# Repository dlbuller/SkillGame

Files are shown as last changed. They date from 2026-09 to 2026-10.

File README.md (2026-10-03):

<div align="center">

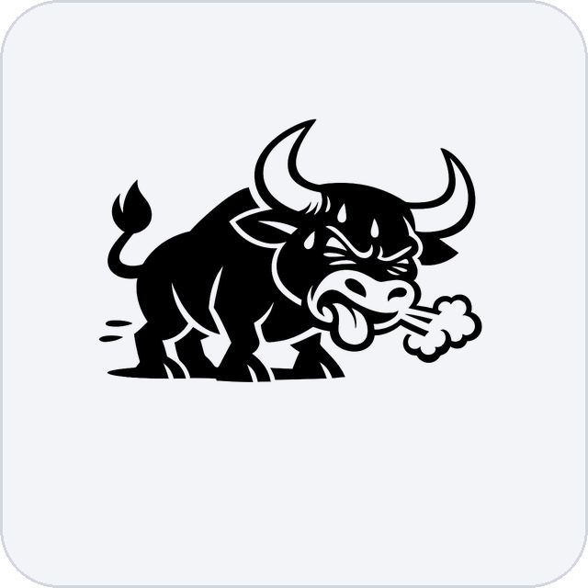
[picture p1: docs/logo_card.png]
WezeBull Games


# SkillGame

**A modern recreation of the 1955 [Bally Skill-Roll](https://www.ipdb.org/machine.cgi?id=4331) coin-roll arcade game** — real coin, real hardware, modern brains.

`ALL HUFF · NO BULL` — WezeBull Games







</div>

---

The player rolls a physical coin up the playfield. It rides the rails, skims the scoring holes, and drops into one to score. Climb the levels without losing the coin to a **gobble hole** — or **tilting** — and you win. A mini-PC runs the whole machine over four FT232H boards and shows the backglass, diagnostics and operator console on a touch monitor.

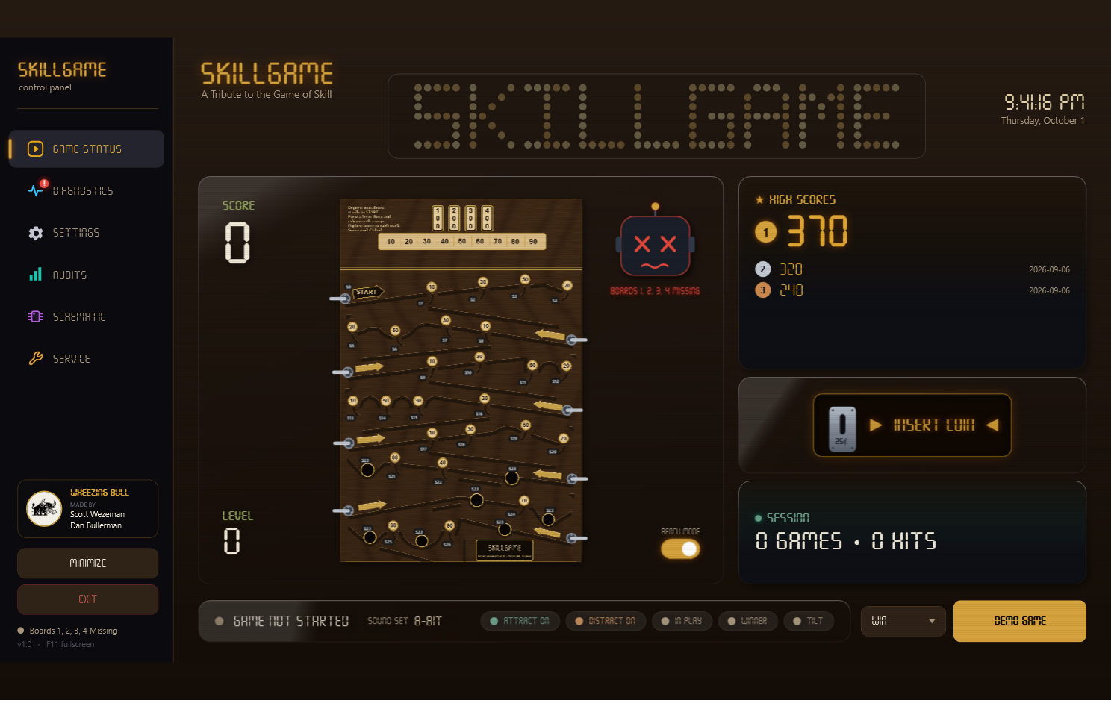
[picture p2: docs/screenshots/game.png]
Game Status


## Contents

- [How it plays](#how-it-plays) · [Features](#features) · [Screens](#screens) · [Themes](#themes) · [Hardware](#hardware) · [Build the board](#build-the-board) · [Software updates](#software-updates) · [Build &amp; run the app](#build--run-the-app) · [Layout](#layout)

## How it plays

1. **Insert a coin** — a real coin drops through the mech and arms a shot.
2. **Roll it up the playfield.** The coin rides *on top* of the rails and skims across the scoring holes.
3. **Drop it in a hole to score** — `10`–`90`, then the big `100 / 200 / 300 / 400` reels.
4. **Beware the gobble holes.** As you climb into the danger levels the machine flashes its lights and plays a **distract** effect *before* your shot — a real Skill-Roll trick to make you flinch. A miss ends the game.
5. **Land the Winner hole to win.** Tilt the machine too hard and it's game over.

## Features

- 🎯 **Game Status backglass** — live score, level, lamps and the coin animation, driven by the real switch reads.
- 🔧 **Diagnostics** — a live switch map and lamp map, a one-touch **Self-Test** that lights every lamp / pulses the coils / sweeps the LED strip, per-lamp **Identify** blink, and **stuck-switch** detection that turns a tile solid red.
- 📊 **Audits** — plays, wins, hits, high scores and time played, watched over by the auditor gremlin. Demo/attract games are excluded, so the numbers only count real play.
- 🛠️ **Service** — a single-screen operator console for volume, quiet hours, tilt sensitivity and the rest.
- 🎨 **12 themes** — Classy, Fun, Plain, Blackout, Vintage, Maple, Midnight, Synthwave, Lava, Circuit, Galaxy, Ruby; each reskins the whole UI *and* the playfield art. (Settings → Theme)
- ⬆️ **In-app software updates** — checks the WezeBull server, shows the release notes, and installs **any** version forward or back (Service → Check for Updates); it flags new versions on boot. Updates are unzip-and-copy + relaunch — no PC reboot.
- 🗺️ **Interactive schematic page** — a clickable system diagram with crossing-free animated wiring, plus one-tap access to the BOM, fuses, system hookup, full schematic, FT232H pinout and a 3D board viewer.
- 👻 **Attract / demo mode** — with no boards attached the app plays itself, so you can see the whole thing run on a laptop.
- ✅ **56 unit tests** over the game core — scoring, levels, tilt, coin gate, the spring-return lock pulses, stuck detection and the switch router.

## Screens

| | |
|---|---|
| **Schematic** — interactive, clickable system diagram | **Diagnostics** — live switch + lamp maps, self-test |
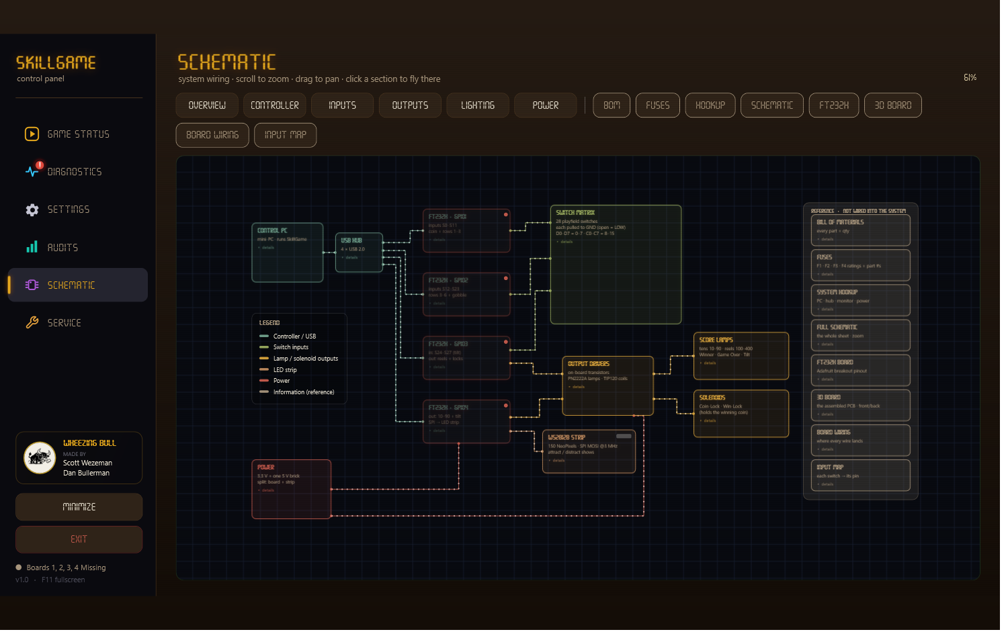
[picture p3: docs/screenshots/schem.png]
Schematic
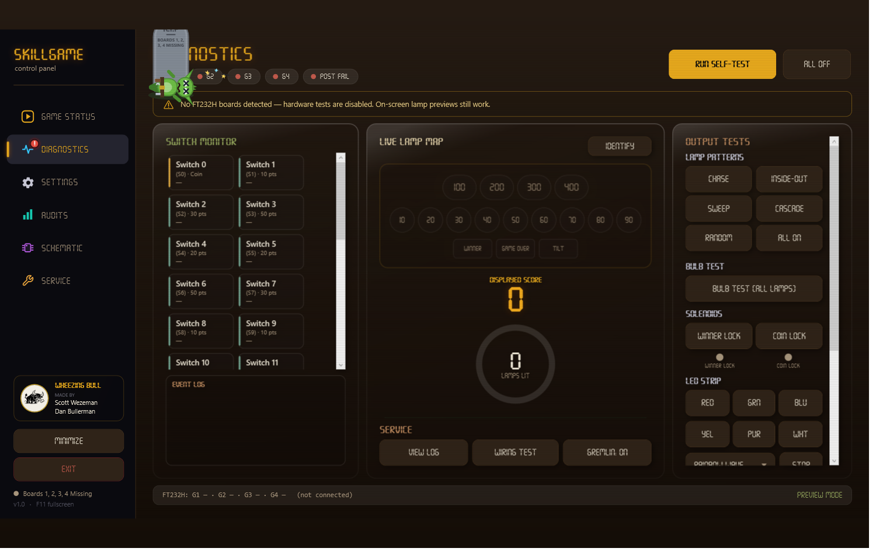
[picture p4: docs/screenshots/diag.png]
Diagnostics
|  |  |
| **Audits** — plays, wins, hits, high scores (the gremlin) | **Service** — one-page operator console |
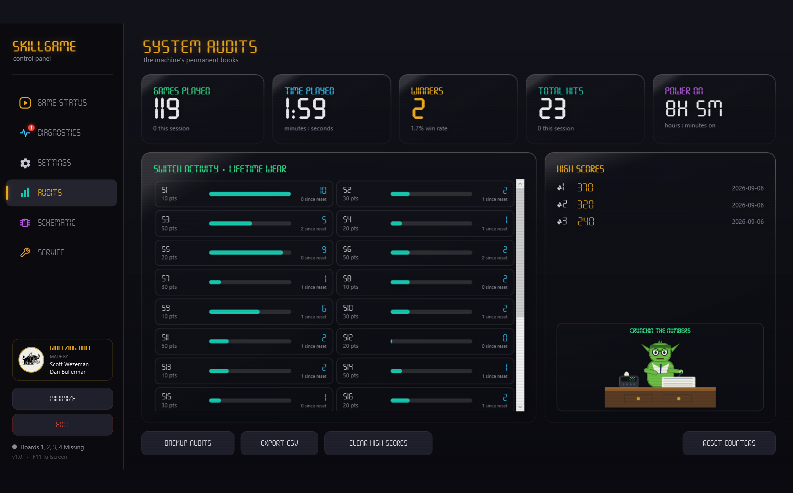
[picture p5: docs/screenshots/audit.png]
Audits
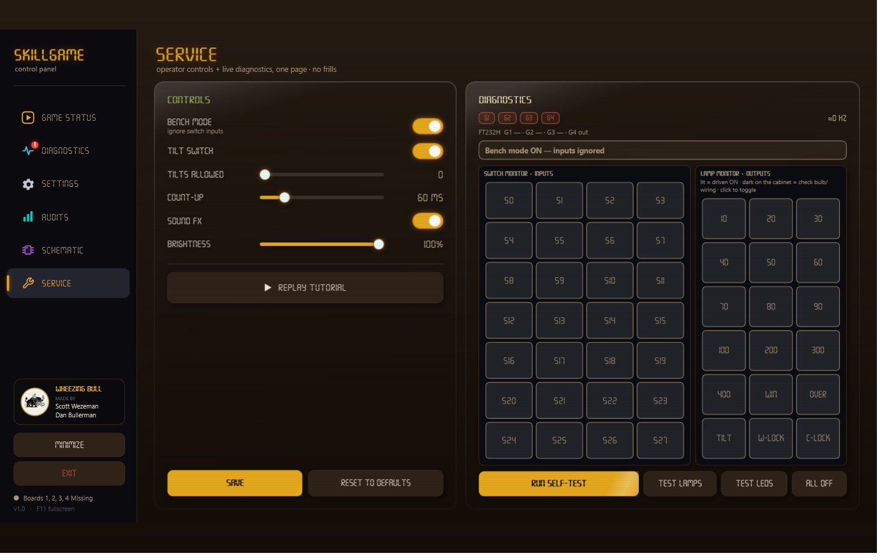
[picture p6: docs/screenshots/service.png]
Service
|  |  |

## Themes

Pick a look in **Settings → Theme**. Each of the **12 themes** reskins the whole UI *and* the playfield art — and every board below is geometry-matched to the original, so the coin paths never move:

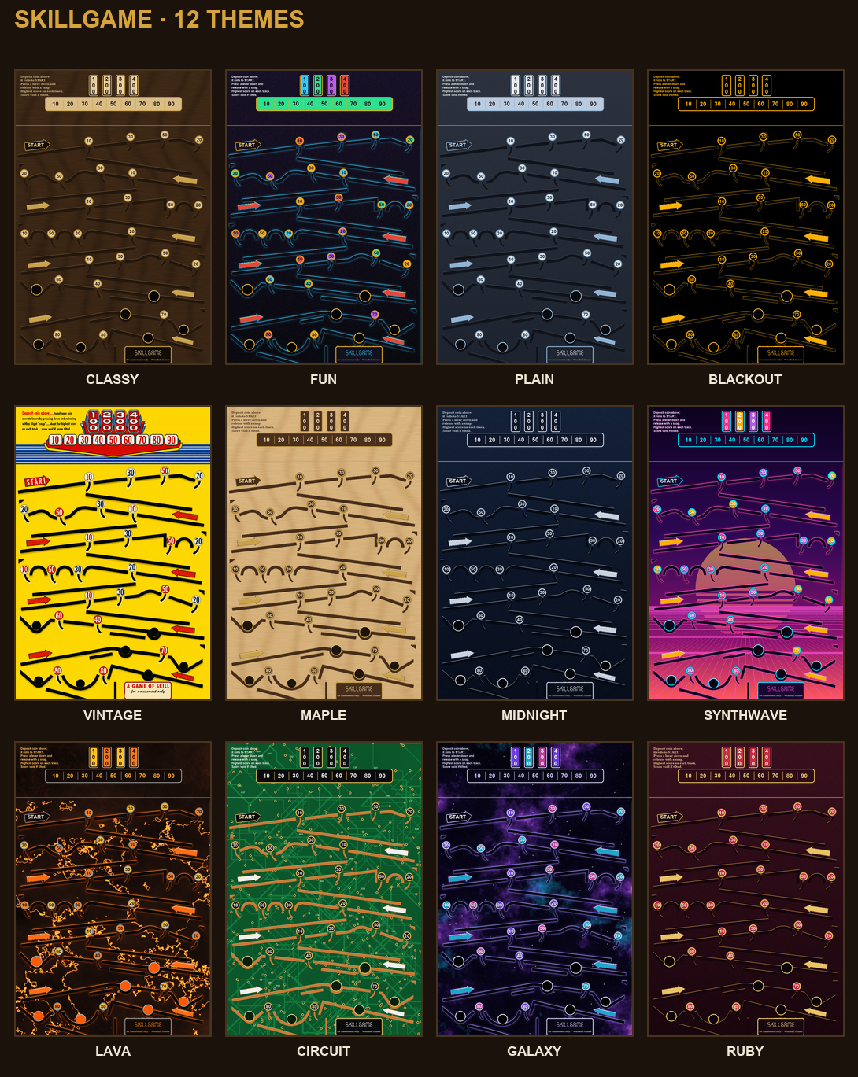
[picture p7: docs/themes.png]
SkillGame themes


**Classy** (walnut &amp; brass, the default) · **Fun** (arcade neon) · **Plain** (cool slate) · **Blackout** (OLED black &amp; amber) · **Vintage** (the 1949 look) · **Maple** · **Midnight** (navy &amp; chrome) · **Synthwave** · **Lava** · **Circuit** · **Galaxy** · **Ruby** (garnet &amp; gold).

## Hardware

The control board is a custom KiCad 9 design driven by **four Adafruit FT232H** breakouts over USB (MPSSE mode). Everything the software touches maps 1:1 to a real pin.

| Section | What it does |
|---|---|
| **Inputs** | 28 switches on GPIO1–3 (S23 = 7 parallel gobble holes). Commons run on 3.3 V — the FT232H inputs are **not** 5 V-tolerant. |
| **Score lamps** | 16 lamps via PN2222A drivers → 16 off-board **#555 wedge LED bulbs**. |
| **Solenoids** | Coin-Lock + Winner-Lock — **spring-return** coils (plunger out at rest blocks a coin with no power; a brief **pulse** retracts it to drop the coin, never held). TIP120 Darlingtons with 1N4004 flyback, fused (F1/F2 T2A). |
| **LED strip** | 150-pixel WS2812b on GPIO4's SPI line, on its own 5 V feed. |
| **Power** | 3.3 V → J1 (switch commons). One 5 V / 10 A brick splits into two fused branches — **F3** (T3.5A) → J3 (lamps + coils, ~2.7 A) and **F4** (T5A) → the strip's own LED± feed (~3.6 A, firmware brightness-capped). The strip never runs through the board. |

**The lamps are LEDs, wired honestly.** Each score lamp is a non-polar #555 wedge LED bulb in a twist-lock socket. Because the bulb is pre-resistored, the board's lamp positions (R30–R62) are **0 Ω links** — and a 6.3 V bulb on the 5 V rail runs safely under-driven. The **100 / 200 / 300 / 400** holes each drive **two** bulbs in parallel for double brightness.

| Score-lamp bulbs (schematic) | Board (3D) | System hookup |
|---|---|---|
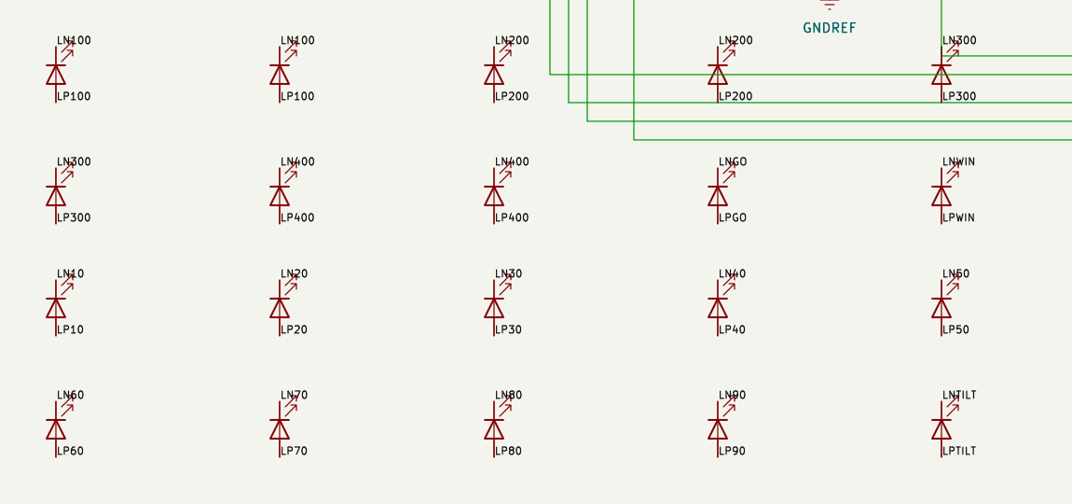
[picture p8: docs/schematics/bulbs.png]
Lamp bulbs
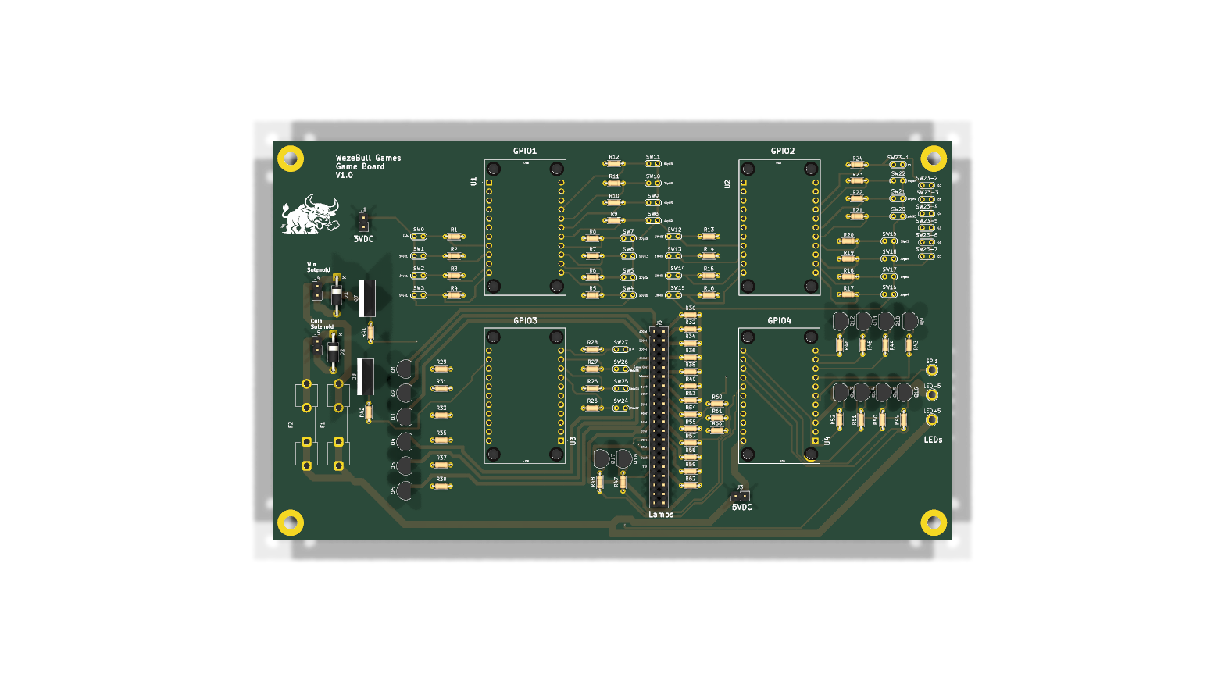
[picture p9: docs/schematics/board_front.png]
Board front
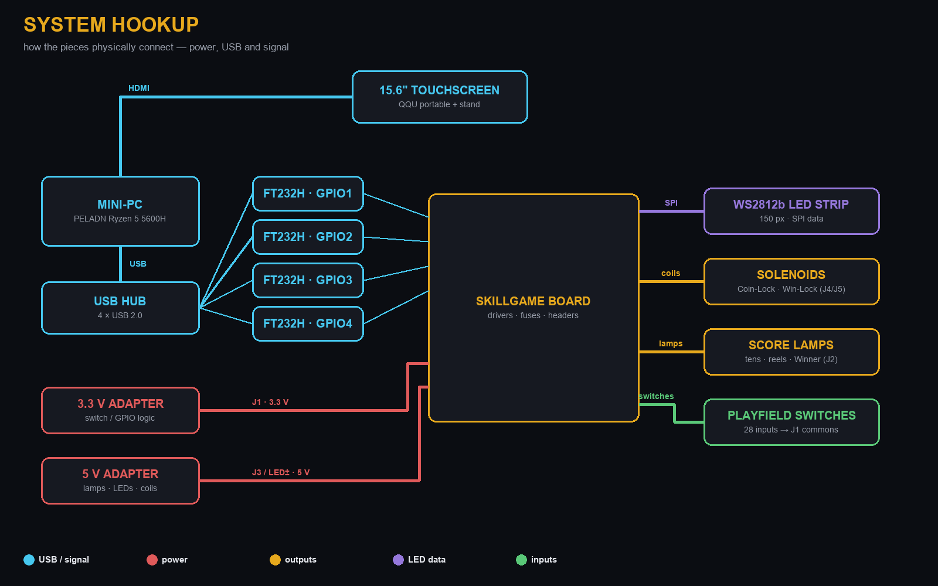
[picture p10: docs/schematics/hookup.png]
Hookup
|  |  |  |

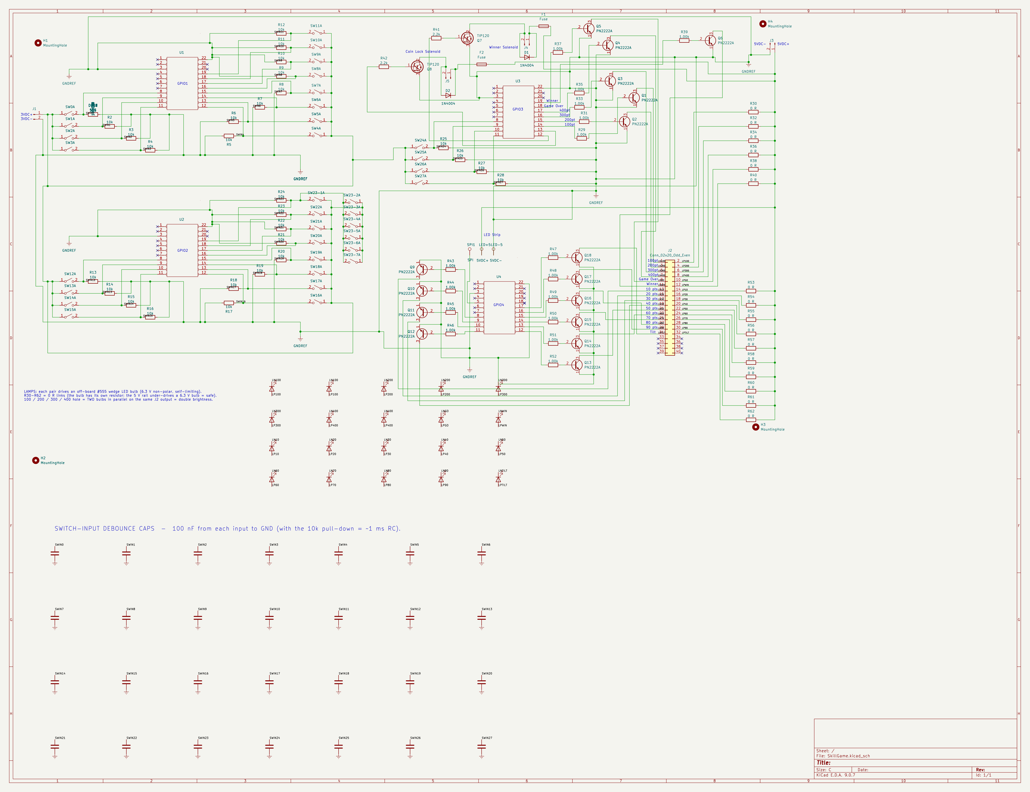
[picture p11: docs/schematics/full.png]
Full schematic


## Build the board

Everything you need to source and assemble it is in [`docs/`](docs/):

- 📋 **[Sourced BOM (xlsx)](docs/SkillGame%20BOM%20(sourced).xlsx)** — every part with vendor links + prices (mini-PC, monitor and power included).
- 📖 **[Assembly guide (PDF)](docs/SkillGame%20Assembly%20Guide.pdf)** — an IKEA-style, step-by-step build, parts list on page one.

The KiCad 9 project (schematic + PCB) lives in [`hardware/`](hardware/) — ERC clean and DRC clean.

## Software updates

The machine updates itself over the internet — no USB stick, no reflashing.

**For the operator:** **Service → Check for Updates** lists every published version (newest first, latest tagged). Pick any one to **install forward or roll back** — it shows the release notes, downloads, verifies the file, swaps it in and relaunches. It's unzip-and-copy only: **no PC reboot.** New versions are flagged automatically on boot and every few hours.

**Where it comes from:** releases are hosted free from this repo's [`update/`](https://github.com/dlbuller/SkillGame/tree/main/update) folder over `raw.githubusercontent.com` — [`versions.json`](https://github.com/dlbuller/SkillGame/blob/main/update/versions.json) is the list the app reads. Cut a new version with one command:

```bash
powershell -File tools\publish-update.ps1 -Version 1.1.0 -Notes "What changed."
```

That builds, zips, hashes, writes the manifest + release notes + CHANGELOG, updates the version list, and pushes — the app sees it within a couple of minutes.

## Wiring

Every connector and input is labeled so the board can be wired from the wire side — the labeled board below (and the switch-input pin map + J2 lamp pinout in the guide) show where each wire lands. These are on the app's Schematic page too (**BOARD WIRING** / **INPUT MAP**).

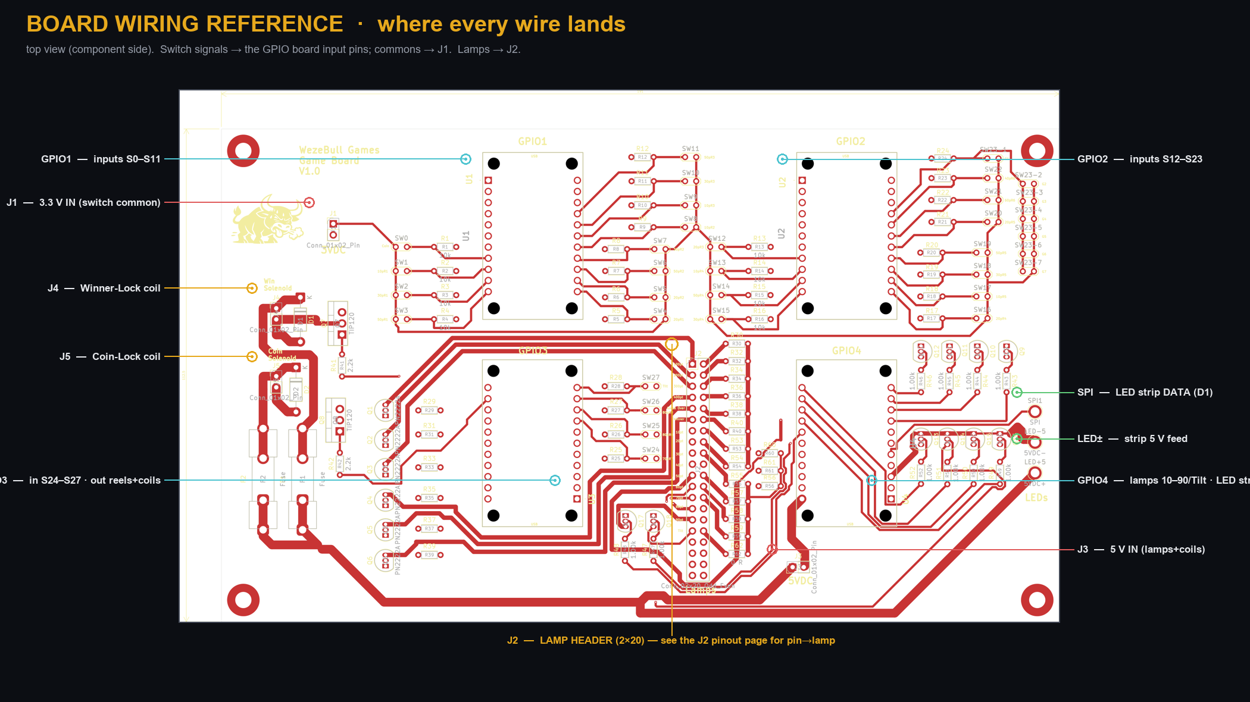
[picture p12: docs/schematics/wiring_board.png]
Board wiring reference


> **Switches:** each hole uses an **arcade coin switch** — a snap-action switch with an 85 mm wire actuator that pokes up through a playfield slot; the rolling coin trips the wire (the long wire gives it a feather-light touch). It mounts hidden under the playfield and wires like any SPDT switch (~$3.99 ea, cheaper in packs).

## Build &amp; run the app

```bash
cd SkillGameWpf
dotnet build -c Debug -p:Platform=x64
```

```bash
cd "SkillGame Source/SkillGame.Tests"
dotnet test
```

The app targets `net8.0-windows` (WPF, x64). With no FT232H boards attached it runs in demo/preview mode, so you can try it on any Windows machine.

## Layout

| Folder | What it is |
|---|---|
| `SkillGameWpf/` | The WPF (.NET 8) front-end / operator console — Game Status, Diagnostics, Settings, Audits, Schematic, Service. |
| `SkillGame Source/SkillGame/` | The UI-agnostic game core (engine, switch map, audits, hardware coordinator). The WPF app links these files directly. |
| `SkillGame Source/SkillGame.Tests/` | xUnit tests for the core. |
| `hardware/` | The KiCad 9 schematic + PCB for the WezeBull Games control board. |
| `docs/` | Sourced BOM, IKEA-style assembly guide, and the schematic-page images. |

## Credits

Scott Wezeman &amp; Dan Bullerman — **WezeBull Games**. *All huff, no bull.*

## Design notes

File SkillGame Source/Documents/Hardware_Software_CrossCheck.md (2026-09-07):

# SkillGame — Hardware ↔ Software Cross-Check

**Sources reconciled:**
1. **Software** — `GPIOFunctions` / `GPIOFunctions.Switches.cs` (pin maps + per-switch handlers)
2. **Spec** — `tofrom.xlsx` ("to/from" pin list + switch matrix)
3. **Playfield** — annotated `Switch Locations.jpg`
4. **Board** — `SkillGame.kicad_sch`, verified via an exported netlist (`kicad-cli sch export netlist`, parsed programmatically)

## Verdict

**Everything lines up.** All four sources agree on every switch, point value, row, lamp, and solenoid. The PCB wires each FT232H pin to exactly the function the software expects. No electrical or logical mismatches were found. The only issues are cosmetic (listed at the end).

## What the board actually is (from the netlist)

| Item | Count | Notes |
|---|---|---|
| FT232H sockets | 4 | refs **U1–U4** (22-pin module footprint) |
| Playfield switches | 34 | S0–S27, plus S23 split into 7 parallel gobble switches (SW23-1…SW23-7) |
| Lamp drivers (PN2222A) | 16 | score reels, tens lamps, tilt, game-over, winner |
| Solenoid drivers (TIP120) | 2 | Coin Lock (Q7), Win Lock (Q8) |
| Flyback diodes (1N4004) | 2 | across the two solenoids |

**U1→GPIO1, U2→GPIO2, U3→GPIO3, U4→GPIO4** — confirmed by which switches/loads each socket wires to. Identity is assigned by the FTDI **serial number** in firmware, not the socket.

## Verified pin map

Format: `FT pad` (logical pin in code) → switch/load. Inputs active-High (3.3 V + 10 k pull-down). Full color version: `SkillGame_GPIO_Map.html`.

### GPIO1 / U1 — inputs (Coin + Rows 1–3)
`D4`(4)→S0 Coin · `D5`(5)→S1 10 · `D6`(6)→S2 30 · `D7`(7)→S3 50 · `C0`(8)→S4 20 · `C1`(9)→S5 20 · `C2`(10)→S6 50 · `C3`(11)→S7 30 · `C4`(12)→S8 10 · `C5`(13)→S9 10 · `C6`(14)→S10 30 · `C7`(15)→S11 50

### GPIO2 / U2 — inputs (Rows 3–6 + Gobble)
`D4`(4)→S12 20 · `D5`(5)→S13 10 · `D6`(6)→S14 50 · `D7`(7)→S15 30 · `C0`(8)→S16 20 · `C1`(9)→S17 10 · `C2`(10)→S18 30 · `C3`(11)→S19 50 · `C4`(12)→S20 20 · `C5`(13)→S21 60 · `C6`(14)→S22 40 · `C7`(15)→**S23 Gobble (G1–G7, 7 switches paralleled)**

### GPIO3 / U3 — inputs (Rows 7–8, Tilt) + reel/solenoid outputs
Inputs: `D4`(4)→S24 70 (Row 7) · `D5`(5)→S25 80 (Row 8) · `D6`(6)→S26 80 (Row 8) · `D7`(7)→S27 Tilt
Outputs: `C0`(8)→Coin Lock **[TIP120 Q7]** · `C1`(9)→Win Lock **[TIP120 Q8]** · `C2`(10)→100 · `C3`(11)→200 · `C4`(12)→300 · `C5`(13)→400 · `C6`(14)→Game Over · `C7`(15)→Winner  *(lamps via PN2222A Q1–Q6)*

### GPIO4 / U4 — tens-lamp outputs + NeoPixel
`D1`(1)→**WS2812b data (SPI MOSI, 150 px @ 5 V)** · `D4`(4)→10 · `D5`(5)→20 · `D6`(6)→30 · `D7`(7)→40 · `C0`(8)→50 · `C1`(9)→60 · `C2`(10)→70 · `C3`(11)→80 · `C4`(12)→90 · `C5`(13)→Tilt lamp · `C6`(14)/`C7`(15)→**NC**  *(lamps via PN2222A Q9–Q18)*

## Playfield scoring (per hole)

| Row (level) | Holes (points / switch) |
|---|---|
| 0 | Coin Up / S0 |
| 1 | 10/S1 · 30/S2 · 50/S3 · 20/S4 |
| 2 | 20/S5 · 50/S6 · 30/S7 · 10/S8 |
| 3 | 10/S9 · 30/S10 · 50/S11 · 20/S12 |
| 4 | 10/S13 · 50/S14 · 30/S15 · 20/S16 |
| 5 | 10/S17 · 30/S18 · 50/S19 · 20/S20 |
| 6 | 60/S21 · 40/S22 · G1,G2 (S23) |
| 7 | 70/S24 · G3,G4 (S23) |
| 8 | 80/S25 · 80/S26 · G5,G6,G7 (S23) |
| — | Tilt / S27 |

## Cosmetic issues (no functional impact)

1. **Stale comment block** — *Resolved (2026-07 refactor).* Levels now live in `SwitchMap.cs` as data (S24 = Level 7, S25/S26 = Level 8); the old per-pin comment block is gone.
2. **Score-sound keys** — *Resolved.* `GameEngine.Hit` now sends `"<points> pts"` (with the space, matching `AudioFunctions` and the diagnostics preview) and Gobble/Tilt play `"Game Over"`, so score/end sounds actually play. Covered by unit tests.
3. **Socket vs. serial** — the software binds each device by serial (`GPIO1`…`GPIO4`), and the PCB already silk-labels the sockets **GPIO1–GPIO4** (U1–U4), which is exactly right. Just confirm at assembly that the module programmed `GPIOn` goes in the socket labeled `GPIOn`.
4. **Symbol name** — the FT232H socket symbol is named `Conn_01x11_Socket_FT232H` but exposes ~22 module pins. Cosmetic only.

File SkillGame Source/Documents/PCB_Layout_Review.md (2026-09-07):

# SkillGame — PCB Layout Review

**Board:** `SkillGame.kicad_pcb` (original lives in `OneDrive…\SkillGame MiniPC\SkillGame Board\`)
**Renders:** `SkillGame_PCB_top.png` (top copper + silk), `SkillGame_PCB_bottom.png` (bottom copper + GND pour)
**Method:** rendered both copper layers with `kicad-cli pcb export svg`, parsed the board for stats, and ran `kicad-cli pcb drc`.

## Bottom line

The board is **complete, correct, and manufacturable** — but the routing/placement is **not streamlined**. It passes every rule; it's just hand-routed and loose. Nothing here is a "must fix" — these are tidiness/robustness improvements for a v2 spin, not defects.

## Objective results

| Check | Result |
|---|---|
| DRC violations | **0** |
| Unconnected (unrouted) items | **0** |
| Board size | 200.8 × 121.6 mm (2-layer) |
| Footprints | 135 (all through-hole) |
| Track segments | 869 (575 top / 294 bottom) |
| Vias | 7 |
| Copper zones | 1 — `GNDREF` ground pour on **B.Cu** |

## What's good

- **Electrically finished** — fully routed, 0 DRC errors, 0 unconnected nets.
- **Has a ground plane** — bottom-side `GNDREF` pour.
- **Clean mechanicals** — rounded outline, four corner mounting holes, sensible size.
- **Professional touches** — title block "WezeBull Games – Game Board V1.0" with logo; the four FT232H sockets are silk-labeled **GPIO1–GPIO4** (resolves the serial/assembly concern).
- **Logical edge I/O** — power (3VDC / 5VDC) and load connectors (LEDs, solenoid) at the board edges.

## What isn't streamlined (improvements, most-impactful first)

1. **Placement forces long fan-out.** The 28 input pull-down resistors and 18 driver transistors sit in banks *away* from the FT232H pins they serve, so each pin runs a long trace. **Fix:** put each pull-down / driver right next to its socket pad — most of the messy routing then disappears on its own.
2. **Top-layer "spaghetti."** Long parallel bundles snake left-to-center with diagonal fans out of GPIO3/GPIO4. Functional, but longer/busier than needed (a symptom of #1).
3. **Fragmented ground return.** 294 traces on the bottom but only 7 vias, so the `GNDREF` pour is cut into islands. For the solenoids (inductive kick) and the 3 MHz WS2812b line, move more signals off the bottom and add ground-stitching vias.
4. **Uneven density.** Left/center is packed; the right third (GPIO4 + LEDs connector) is sparse. Rebalancing shortens cross-board runs.
5. **Confirm current-carrying widths.** Set a net class so the 5 V NeoPixel feed and solenoid traces are wider than signal traces.

## Note

Re-routing is a hands-on KiCad task and was **not** automated — doing so blindly would more likely break the current clean DRC than help. If a v2 is wanted, start with item #1 (placement); the rest follows.

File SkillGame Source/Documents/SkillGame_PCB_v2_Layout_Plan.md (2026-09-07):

# SkillGame — PCB v2 Layout Plan (tidy the routing, keep it correct)

**Status of the current board:** electrically **complete and correct** — 0 DRC violations, 0 unconnected
nets, ground pour present, sockets silk-labeled GPIO1–GPIO4. It works and is manufacturable. The only
weakness is that the **layout** is hand-routed and loose. This plan is how to make it *nice* without
breaking what already works.

> **Why this is a plan and not an automated edit:** re-placement/re-routing is a visual, iterative KiCad
> task. Doing it blind (scripted, no canvas, no interactive DRC) would almost certainly introduce new
> violations and could leave the board unroutable — strictly worse than the loose-but-working board you
> have. Work through this interactively in KiCad instead. **The schematic is verified correct — do not
> change it; only move footprints and re-route copper.**

## Ground rules
1. **Branch it.** Copy the board folder first (`SkillGame_v2/`) so v1 stays intact.
2. **Never touch the schematic / netlist.** Placement + routing only. Re-import netlist only if you
   deliberately changed the schematic (you shouldn't).
3. **Re-run DRC after every stage** (`kicad-cli pcb drc SkillGame.kicad_pcb`) and keep it at **0**.
4. Do it in the order below — each stage makes the next one easier.

## Stage 1 — Placement (biggest win, do this first)
The messy routing is a *symptom* of placement. Fix placement and most traces shorten on their own.
- For each FT232H socket (U1–U4), pull its **own** support parts right up against it:
  - the 28 input **10 kΩ pull-downs** next to the pins they hold down,
  - the 16 **PN2222A** lamp drivers + their 1 kΩ base / 220 Ω limit resistors beside the pins that drive them,
  - the 2 **TIP120** + 2.2 kΩ base + **1N4004** flyback + fuse next to GPIO3's solenoid pins.
- Group by socket so each board becomes a self-contained cluster (U1 cluster, U2 cluster, …).
- Keep the edge connectors (J1 3VDC, SPI1 5VDC, J2 lamp harness, solenoid conn) where they are — on the edges.

## Stage 2 — Re-route the (now short) signals
- Rip up the top-layer "spaghetti" (Route → un-route, or delete the long segments) and re-route each
  cluster locally. With parts adjacent to their pins, most runs become short and straight.
- Keep signal on the top layer; reserve the bottom for ground (Stage 3).

## Stage 3 — Solid ground return
- The current bottom pour is cut into islands (294 bottom traces, only **7 vias**).
- After Stage 2 there should be far fewer bottom signals. Then **add ground-stitching vias** — a loose
  grid of GND vias across the pour, and especially:
  - a via near every driver transistor's emitter/ground,
  - vias flanking the 3 MHz WS2812b data line and the solenoid traces (inductive kick).
- Re-pour (`B.Cu` GNDREF) and confirm the pour is continuous, not fragmented.

## Stage 4 — Trace widths (net classes)
- Add net classes in Board Setup → Net Classes:
  - **PWR_5V** (WS2812b +5 V feed) and **PWR_SOL** (solenoid V+) → wider (e.g. 0.6–0.8 mm),
  - **PWR_LAMP** → medium,
  - default signal class stays thin.
- Assign the 5 V / solenoid / lamp-V+ nets to those classes, then re-route (or "change width") those nets.
  Do this *after* routing so you don't fight the autorouter-less manual routes.

## Stage 5 — Rebalance & finish
- The right third (GPIO4 + LED connector) is sparse while the left/center is packed. Nudge clusters to
  even out density; it shortens cross-board runs.
- Final checks: `kicad-cli pcb drc` = 0, ratsnest fully routed, pour continuous, silkscreen still legible,
  fab outputs (Gerbers/drill) regenerate cleanly.

## Definition of done
- 0 DRC, 0 unrouted.
- Each FT232H's support parts sit beside it; no long cross-board fan-out.
- Continuous bottom ground pour with stitching vias.
- Power/solenoid nets on wider classes.
- v1 board preserved untouched in its own folder.

*Happy to pair on this interactively in KiCad — I can drive placement/routing decisions stage by stage
and re-run DRC with you, which is the safe way to do it.*

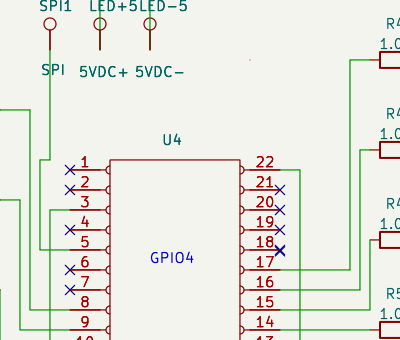
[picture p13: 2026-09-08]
docs/schematics/g4.png

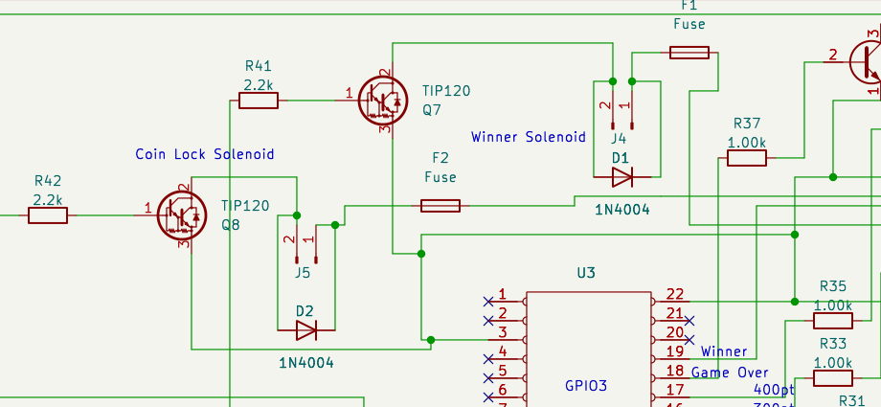
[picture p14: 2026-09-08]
docs/schematics/sol.png

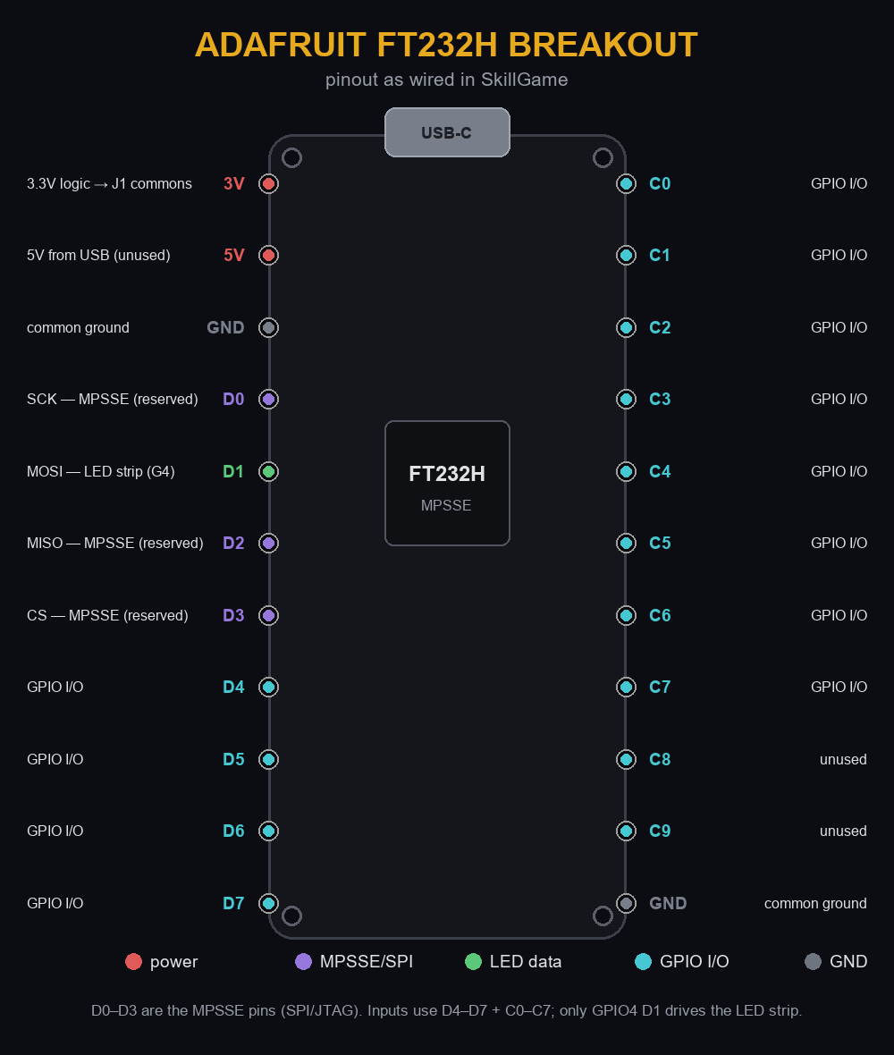
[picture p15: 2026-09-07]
docs/schematics/ftdi.png

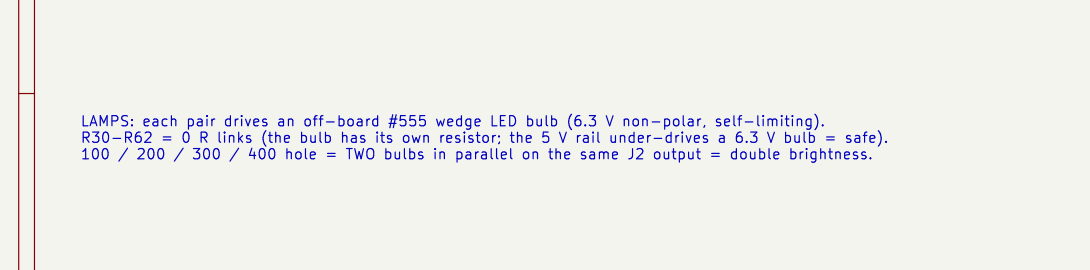
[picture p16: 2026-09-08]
docs/schematics/lampnote.png

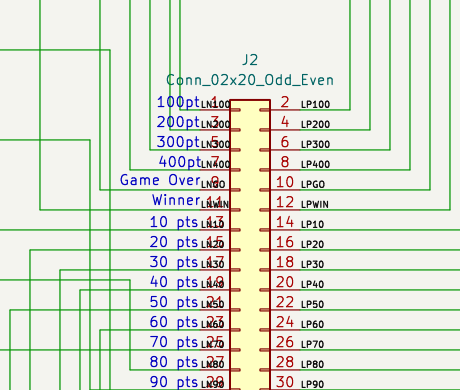
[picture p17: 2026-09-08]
docs/schematics/j2.png

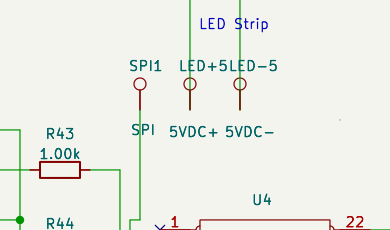
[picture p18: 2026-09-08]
docs/schematics/strip.png

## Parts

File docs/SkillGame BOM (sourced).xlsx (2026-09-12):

SkillGame — Sourced Bill of Materials
Board parts from the KiCad project + the mini-PC / monitor / power. Prices representative (Sept 2026); vary by vendor & qty. 'Line est' = what you'll actually spend on that row.
Category | Ref / Where | Part | Qty | Buy as | Vendor | Unit/Pack $ | Line est $ | Link | Notes
BOARD
Controller | U1–U4 | Adafruit FT232H Breakout (USB-C) | 4 | each | Adafruit #2264 | $14.95 | $59.80 | link (https://www.adafruit.com/product/2264) | one per board; also Amazon/DigiKey/Mouser
Drivers | Q1–Q6, Q9–Q18 | PN2222A NPN transistor TO-92 | 16 | 50-pack | Amazon B07GPPLQYF | $7.49 | $7.49 | link (https://www.amazon.com/PN2222A-Small-Signal-Transistor-Piece/dp/B07GPPLQYF) | lamp/reel drivers
Drivers | Q7, Q8 | TIP120 Darlington TO-220 | 2 | 7-pack | Amazon B07F5C1FF1 | $8.00 | $8.00 | link (https://www.amazon.com/STMicroelectronics-TIP120-Transistor-Darlington-3-Pin/dp/B07F5C1FF1) | solenoid drivers
Diodes | D1, D2 | 1N4004 rectifier DO-41 | 2 | 100-pack | Amazon B0CN69DV38 | $6.49 | $6.49 | link (https://www.amazon.com/100-PCS-1N4004-IN4004-diode/dp/B0CN69DV38) | solenoid flyback
Resistors | R1–R29 + bases | 1/4 W resistor assortment (10k/1k/2.2k) | 46 | kit | SparkFun COM-10969 | $7.95 | $7.95 | link (https://www.sparkfun.com/resistor-kit-1-4w-500-total.html) | 28×10k pull-downs, 16×1k bases, 2×2.2k TIP120 bases (kit covers all)
Jumpers | R30–R62 | 0 Ω lamp links (bridge with wire / solder) | 16 | each | in kit / solder | $0.00 | $0.00 | link (https://www.sparkfun.com/resistor-kit-1-4w-500-total.html) | lamp positions — the #555 bulb self-limits, so these are 0 Ω links, not resistors
Filtering | C1–C28 | 0.1 uF (100 nF) ceramic cap, 0805 SMD | 28 | 50-pack | Amazon (100nF 0805) | $7.49 | $7.49 | link (https://www.amazon.com/s?k=100nF+0805+capacitor) | one per switch input to GND — debounce + noise filter (~1 ms RC with the 10k pull-down); on the board's back side
Protection | F1, F2 | Littelfuse 0218002.MXP T2A 5×20mm 250V | 2 | each | DigiKey 777600 | $0.68 | $1.36 | link (https://www.digikey.com/en/products/detail/littelfuse-inc/0218002-MXP/777600) | slow-blow; for the small 5V solenoids
Protection | F3 | Bussmann GDC-3.5A T3.5A 5×20mm 250V | 1 | each | DigiKey/Mouser | $1.10 | $1.10 | link (https://www.digikey.com/en/products?keywords=GDC-3.5A) | inline fuse on the BOARD branch (5V to J3: lamps + coils, ~2.7A worst). The strip is a separate fused branch (F4) off the same 5V brick - never through J3.
Protection | F4 | Bussmann GDC-5A T5A 5×20mm 250V | 1 | each | DigiKey/Mouser | $1.10 | $1.10 | link (https://www.digikey.com/en/products?keywords=GDC-5A) | inline fuse on the LED strip's branch off the shared 5V brick. Strip is firmware brightness-capped (~40%, MaxBrightness) so 150px stays under ~3.6A; T5A rides that with headroom.
Protection | F1, F2 holders | Keystone 3517 fuse clip 5×20mm | 4 | each | DigiKey 316010 | $0.30 | $1.20 | link (https://www.digikey.com/en/products/detail/keystone-electronics/3517/316010) | 2 clips per fuse (F1/F2)
Protection | F3/F4 holders | uxcell inline screw-type 5×20mm fuse holder, 18 AWG leads | 1 | 5-pack | Amazon B07SM5KYZ7 | $6.99 | $6.99 | link (https://www.amazon.com/uxcell-Inline-Screw-Holder-Gauge/dp/B07SM5KYZ7) | one for F3 (board branch), one for F4 (strip branch); the 5-pack covers both with spares. 18 AWG handles either branch.
Protection | 5V split | 2-way terminal block / Wago 221 lever nuts | 1 | pack | Amazon B0B3SVL3WK | $8.99 | $8.99 | link (https://www.amazon.com/s?k=wago+221+lever+nuts) | splits the single 5V brick into the F3 (board) and F4 (strip) branches; commons the grounds too
Connectors | J2 | 2×20 (40-pin) 2.54mm header | 1 | each | generic | $1.00 | $1.00 | link (https://www.amazon.com/s?k=2x20+pin+header+2.54mm) | lamp/output connector
Connectors | J1,J3,J4,J5 | 2-pin 2.54mm header | 4 | kit | generic | $3.00 | $3.00 | link (https://www.amazon.com/s?k=2.54mm+pin+header+kit) | power in + solenoid out
Playfield | Score / gobble switches | Arcade COIN SWITCH, 85mm straight wire actuator (SPDT) | 34 | each | DIY Retro Arcade / eBay | $3.99 | $135.66 | link (https://www.diyretroarcade.com/products/coin-switch-with-straight-long-wire-for-arcade-coin-mech) | the long wire pokes up through a playfield slot; the rolling coin trips it (the 85mm wire = tiny actuation force, made for coins). Mounts hidden UNDER the playfield. Wires like any SPDT switch (use COM + NO). 28 inputs; the 7 gobble switches parallel onto S23. ~$2 ea in 10-packs on eBay/AliExpress.
Lighting | LED strip | WS2812b 150-pixel 5V strip | 1 | each | Amazon B0CFTPT81S | $12.99 | $12.99 | link (https://www.amazon.com/16-4FT-WS2812B-Individual-Addressable-5050SMD/dp/B0CFTPT81S) | 150 addressable px
Lighting | Score lamps | #555 T10 wedge LED, 6.3V non-polar (frosted) | 20 | 25-pack | Amazon (Keiurot) | $18.00 | $18.00 | link (https://www.amazon.com/Pinball-Bulbs-Arcade-Machine-Nonpolarity/dp/B0B1HXP8P1) | 16 lamps + a 2nd bulb on 100/200/300/400 (double bright) = 20; non-polar & pre-resistored, runs safely under-driven on the 5V rail (board R = 0 ohm links)
Lighting | Lamp sockets | T10/#555 wedge socket, pigtail leads | 20 | 25-pack | Amazon B00VDOPPDE | $11.99 | $11.99 | link (https://www.amazon.com/Pieces-Extension-Socket-Holder-Rubber/dp/B00VDOPPDE) | one per bulb; solder its leads to the J2 lamp lines
Actuators | Coin-Lock, Win-Lock | SparkFun Solenoid - 5V (Small), ROB-11015 | 2 | each | SparkFun ROB-11015 | $6.50 | $13.00 | link (https://www.sparkfun.com/solenoid-5v-small.html) | 5 V, 1.1 A, 4.5 ohm, ~5.5 W. SPRING-RETURN push-pull: plunger sits OUT at rest (blocks a coin, zero power) and retracts when energized (drops it). INTERMITTENT duty (25%) - the firmware PULSES it, never holds. T2A fuse each (F1/F2). Same part as Adafruit 2776.
SYSTEM
Computer | mini-PC | PELADN Ryzen 5 5600H, 16GB DDR4 / 512GB SSD | 1 | each | Amazon B0F7R7V9VK | $209.99 | $209.99 | link (https://www.amazon.com/PELADN-Mini-PC-Computer-Triple-Display/dp/B0F7R7V9VK) | 6C/12T Ryzen, Vega gfx, WiFi6, USB3.2 — plenty of headroom
Display | monitor | QQU 15.6" portable touchscreen (with stand) | 1 | each | Amazon B0FHHM1Y7Z | $70.49 | $70.49 | link (https://www.amazon.com/QQU-Portable-Touchscreen-Extenderfor-Compatible/dp/B0FHHM1Y7Z) | 1080P IPS/HDR; USB-C touch + HDMI; incl. stand
USB | hub | 4-port USB 2.0 hub | 1 | each | Amazon/Monoprice | $8.99 | $8.99 | link (https://www.monoprice.com/product?p_id=6631) | one port per FT232H
Power | J1 supply | 3.3 V DC wall adapter (≥1A) | 1 | each | Amazon B07BGW2VXV | $7.99 | $7.99 | link (https://www.amazon.com/3-3V-Adapter-Power-5-5-2-1/dp/B07BGW2VXV) | switch-common / GPIO logic
Power | 5V supply | BTF-LIGHTING 5V 10A 50W (ETL/Class 2) | 1 | each | Amazon B0G4KXT4BL | $27.99 | $27.99 | link (https://www.amazon.com/dp/B0G4KXT4BL) | ONE 5V brick for the whole 5V system. Split at the terminal block: F3 branch to J3 (board: lamps + coils ~2.7A) + F4 branch to the strip (~3.6A capped) = ~6.3A worst, so 10A leaves headroom. ETL-listed / Class 2 - safe for a mains-plugged cabinet. Barrel output: cut the plug or use a barrel-to-screw pigtail into the split.
 |  |  |  |  |  | ESTIMATED TOTAL
 |  | Line est already accounts for quantity (e.g. 4× FT232H). Pack/kit rows are a single purchase that covers the qty.

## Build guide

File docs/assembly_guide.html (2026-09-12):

WezeBull Games

Assembly Guide

# SKILLGAME

A Tribute to the Game of Skill



ALL HUFF · NO BULL

WezeBull Games · build it once, build it right

# Parts list

## everything you need before you start

Qty | Part | What it's for
The board
4 | Adafruit FT232H breakout | USB→GPIO controllers (U1–U4)
16 | PN2222A transistor (TO-92) | lamp / reel drivers
2 | TIP120 Darlington (TO-220) | solenoid drivers (Q7/Q8)
2 | 1N4004 diode | solenoid flyback (D1/D2)
28 | 10 kΩ resistor | switch pull-downs
16 | 1 kΩ resistor | transistor base
16 | 0 Ω jumper (or solder bridge) | lamp links R30–R62 — the #555 bulb self-limits
28 | 100 nF ceramic cap (0805 SMD) | C1–C28 · switch-input debounce/noise (back of board)
2 | 2.2 kΩ resistor | TIP120 base
4 | 5×20 mm fuses · 4 Keystone clips + 2 inline holders | F1/F2 T2A (solenoids) · F3 T3.5A inline (5 V to J3) · F4 T5A inline (strip feed)
1 | 2×20 pin header (J2) | lamp / output connector
4 | 2-pin headers (J1/J3/J4/J5) | power in + solenoid out
~34 | Arcade coin switch (85 mm wire actuator) | 28 inputs (S23 = 7 gobble) · coin trips the wire in the slot
1 | WS2812b LED strip, 150 px | attract / distract shows
20 | #555 wedge LED bulb (6.3 V, non-polar) | 16 lamps + a 2nd bulb on 100/200/300/400 (double bright)
20 | #555 / T10 wedge socket (twist-lock) | one per bulb; solder its leads to the J2 lamp lines
2 | SparkFun Solenoid - 5V (Small) | coin-lock + winner-lock
The system
1 | PELADN Ryzen 5 5600H mini-PC (16 GB / 512 GB) | runs SkillGame
1 | QQU 15.6" portable touchscreen (with stand) | the display · 1080P IPS/HDR touch
1 | 4-port USB 2.0 hub | one port per FT232H
1 | 3.3 V wall adapter | switch / GPIO logic (J1)
1 | 5 V wall adapter — BTF-LIGHTING 5 V 10 A 50 W (ETL) | the whole 5 V system — split to J3 (F3, board) + strip (F4); ~6.3 A worst, 10 A leaves headroom
1 | 2-way terminal block / Wago 221 | splits the 5 V brick into the F3 (board) and F4 (strip) branches; commons the grounds

## Tools

• Soldering iron + solder
• Flush cutters
• Small screwdriver
• Multimeter
• Wire + crimp/ferrules

Before you power up: the 3.3 V adapter goes to J1 (switch commons); the 5 V brick splits to J3 (board) and the strip's LED± feed. Never feed 5 V into J1 — the FT232H inputs are not 5 V-tolerant.

SkillGame Assembly Guide · page 1

1

Meet the four boards

Adafruit FT232H — one per GPIO bank



- Four Adafruit FT232H breakouts, each in MPSSE mode over USB-C — the app talks to all four through the USB hub.
- GPIO1 / GPIO2 read switches; GPIO3 reads the top rows + tilt and drives the 100–400 reels, Winner, Game-Over and the two coil lines; GPIO4 drives the 10–90 + Tilt lamps and clocks the LED strip.
- Pins D0–D3 are reserved (SPI/JTAG) — all switch/lamp I/O lives on D4–D7 and C0–C7. Only GPIO4's D1 is used, for the LED strip.
- Program each board with a unique FTDI serial (GPIO1–GPIO4) so the software binds the right board to the right job no matter which USB port it lands on.
- The FT232H's own 3 V / 5 V pins stay unconnected — the boards are USB-powered.

SkillGame Assembly Guide

2

Solder the drivers

resistors, then transistors — lowest parts first



- Resistors first (they lie flat): 28× 10 kΩ pull-downs, 16× 1 kΩ bases, 2× 2.2 kΩ TIP120 bases. The 16 lamp positions (R30–R62) are 0 Ω links — a jumper wire or solder bridge, since the #555 bulbs self-limit.
- Then the 16 PN2222A transistors (TO-92) — mind the flat/rounded face matches the silk.
- Keep leads short; flush-cut the backs.

SkillGame Assembly Guide

3

Solenoid drivers + fuses

TIP120s, flyback diodes, F1/F2



⚠ TIP120 orientation: collector goes to the coil, emitter to ground. If you are using an older board revision, cross the collector (middle/tab) and emitter (right) leads on Q7 & Q8 — a straight insert wires them backwards and the coils won't switch. The current KiCad files already have this fixed.

- Fit the two TIP120s (TO-220) and the 1N4004 flyback diodes — band matches the silk.
- Install the Keystone 3517 clips and drop in the fuses (see next page).

SkillGame Assembly Guide

3b

Fuse the solenoids

F1 / F2 — one per coil, on the board



- Solder the four Keystone 3517 clips — two per fuse — at the F1 and F2 positions. They only go one way; the fuse snaps in across the pair.
- Drop in the fuses: F1 guards the Winner-Lock coil (J4), F2 the Coin-Lock coil (J5). Both are T2A slow-blow, 5×20 mm (Littelfuse 0218002.MXP).
- Slow-blow (T) rides out the coil's turn-on surge; it opens only on a real short. Any 250 V 5×20 mm part is fine on the 5 V rail.

SkillGame Assembly Guide

3c

The inline 5 V fuses

one brick, split → F3 (board) + F4 (strip)



- One 5 V / 10 A brick feeds a 2-way split (a terminal block). F1/F2 only protect the coils. F3 fuses the board branch — J3, lamps + coils, ~2.7 A worst. The strip is the other branch (see step 6c), fused by F4 — never through J3, because its draw is far larger.
- Neither is on the PCB: from the split, run the board's +5 V through the F3 inline holder to J3, and the strip's +5 V through the F4 inline holder (uxcell 18 AWG, screw-terminal). Leave the ground/return whole and common.
- Fit F3 = T3.5A (Bussmann GDC-3.5A) on the board branch and F4 = T5A (GDC-5A) on the strip branch — both slow-blow, 5×20 mm.

Rule of thumb: a fuse ≈ steady current + inrush headroom, and always below what the wiring can carry. T3.5A suits the board branch (~2.7 A); T5A suits the strip branch (~3.6 A capped).

SkillGame Assembly Guide

4

Headers & sockets

J1–J5, the J2 lamp header, and the 4 FT232H sockets



- Solder the 2×20 header (J2) — the lamp/output connector — and the four 2-pin headers: J1 (3.3 V in), J3 (5 V in), J4 (Winner-Lock), J5 (Coin-Lock).
- Tack one pin first, check the header sits flat and square, then solder the rest — a skewed 40-pin header is miserable to fix.
- Fit the four FT232H sockets with even spacing so the boards sit flat and don't touch. The footprints already have clearance; don't skew them.
- Note which socket is GPIO1–GPIO4 (silk) — it must match the serial you programmed into each board.

SkillGame Assembly Guide

5

Wire the switches

28 inputs → J1 commons, pulled to ground



- 28 inputs across GPIO1–3 (D4–D7, C0–C7). One side of every playfield switch ties to the shared J1 3.3 V common; the other side goes to that switch's FT232H input pin.
- An on-board 10 kΩ pull-down holds each input LOW; closing the switch pulls it to 3.3 V (a real HIGH) and the software reads the hit.
- Keep the common at 3.3 V — never 5 V. The FT232H inputs are not 5 V-tolerant; 5 V on an input can kill the chip.
- The 7 gobble holes all report as one input (S23): wire their switches in parallel so any of them trips it.
- Run it as a harness (see the last pages): one 3.3 V bus wire daisy-chained to every switch, plus one signal wire per switch back to the board.

SkillGame Assembly Guide

5b

Fit the input caps

28× 100 nF on the board's back — debounce & noise



- Each switch input gets a 100 nF (0.1 µF) ceramic cap to GND — C1–C28. With the 10 kΩ pull-down it forms a ~1 ms RC filter that kills contact chatter and noise picked up on the long playfield leads.
- They're SMD 0805 on the back of the board, one tucked next to each pull-down (GND pad on the ground pour, the other to the input). Solder them last.
- Optional but recommended — the game still works without them (the software also debounces), but they make the long switch runs far more reliable.

SkillGame Assembly Guide

6

The score lamps

off-board #555 wedge LED bulbs on J2



- Every score lamp — the tens 10–90, the reels 100–400, and Winner / Game-Over / Tilt — is a #555 wedge LED bulb in a twist-lock socket, off the board.
- Each bulb plugs across one J2 pin pair. The odd pin (left, labelled with the lamp name) is switched by the transistor; the even pin (right) is +5 V through that lamp's 0 Ω link. The labels on J2 tell you which pair is which lamp.
- Solder the socket's two leads to that pin pair. The #555 bulbs are non-polar, so which lead goes to which pin doesn't matter.

Wire it as a harness (see the last pages): a 2×20 plug on J2, fanning out to all the sockets, is far tidier than 40 loose wires.

SkillGame Assembly Guide

6b

Double up the big holes

100 / 200 / 300 / 400 — two bulbs each



- The four high-score holes each drive two #555 bulbs for extra punch. Wire the second bulb in parallel on the same J2 pair as the first.
- Both bulbs' + leads land on the even (+5 V) pin; both other leads on the odd (switched) pin.
- No extra resistor — each bulb self-limits, so both run at full brightness. The transistor easily drives two.

SkillGame Assembly Guide

6c

Coils & the LED strip

solenoids off J4 / J5, strip off SPI



- Coin-Lock → J5, Winner-Lock → J4. These are the fused (F1/F2), TIP120-driven 5 V coils — keep the flyback diode across each coil.
- They are spring-return coils: at rest the plunger is pushed OUT (blocking a coin) with no power. The software fires each as a brief pulse — it retracts to drop the coin, then springs back. They are never held energized (intermittent-duty), so mount each with the plunger blocking its coin path at rest.
- LED strip data → GPIO4's D1 (SPI MOSI). Data is one wire plus a common ground.
- Power the strip on its own branch off the 5 V brick (LED+5 / LED−5 through fuse F4, T5A inline), not through J3, so its heavy draw can't sag the lamp/logic rail. Tie all grounds common.
- Why the separate branch: 150 px at full white is ~9 A. The firmware caps the strip to ~40 % brightness (LightFunctions.MaxBrightness), holding a worst-case frame under ~3.6 A; with the board's ~2.7 A that's ~6.3 A total, which the 10 A brick covers.

SkillGame Assembly Guide

7

Hook up the system

PC · hub · monitor · power



- Mini-PC → HDMI → monitor (the QQU 15.6" touch panel), and its USB-C touch lead back to the PC.
- Mini-PC → USB hub → the four FT232H boards — one hub port per board.
- 3.3 V adapter → J1 (switch commons). One 5 V brick → terminal-block split: the F3 branch → J3 (board: lamps + coils), the F4 branch → the strip's LED± feed. Separate branches so the strip can't sag the board rail.
- Tie every ground together — the 3.3 V return, the 5 V return, the LED strip and the boards all share one common ground, or nothing reads right.
- Double-check J1 is 3.3 V and J3 is 5 V before powering on. They are not interchangeable.

SkillGame Assembly Guide

8

Power on & self-test

let the software check your wiring

- Launch SkillGame, open Diagnostics, and run Self-Test — it lights every lamp, pulses the coils and sweeps the LED strip.
- Use the Switch Monitor to press each playfield switch and confirm it registers (and clears).
- Any input stuck HIGH shows as a fault ring — check that switch's wiring and pull-down.
- Green badge on Diagnostics = all boards present and healthy. You're done. ALL HUFF · NO BULL.

The board back is on the next page for reference, followed by the full schematic.



SkillGame Assembly Guide

# Wiring reference

## where every wire lands on the board



- Every connector and GPIO socket is called out above. J1 = 3.3 V in (switch common), J2 = the 2×20 lamp header, J3 = 5 V in, J4/J5 = the two coils, SPI + LED± = the LED strip.
- Switch signals land on the GPIO board input pins (next page); lamp wires land on J2 (pin→lamp map is on the J2 page).

SkillGame Assembly Guide

IN

Switch-input pin map

which pin every switch wire goes to



Each coin switch is a plain SPDT: COM → the 3.3 V common bus (fed by J1), NO → the FT232H pin shown. NC is unused. The 7 gobble switches all wire in parallel onto the one S23 pin (GPIO2 · C7).

The switch: an arcade coin switch with an 85 mm straight wire actuator (SPDT, ~$3.99 ea; ~$2 in 10-packs). The long wire pokes up through a playfield slot and the rolling coin trips it — light touch, body hidden under the playfield. Wires like any SPDT switch (COM + NO), so no board changes. Same style Bally used.

SkillGame Assembly Guide

# Full schematic

## reference



SkillGame · WezeBull Games

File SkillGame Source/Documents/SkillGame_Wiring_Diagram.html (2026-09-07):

Wiring & Assembly Guide

# SkillGame · Wiring Diagram

How the machine connects: the mini-PC drives four FT232H USB boards; each reads the playfield switches or drives the score lamps / solenoids / NeoPixel strip. Signal flow, the four driver circuits, external power, the board with labels, and the full KiCad schematic.

## System overview

One USB hub off the mini-PC feeds all four FT232H boards (told apart by their FTDI serial, GPIO1–GPIO4). Switches run on a 3.3 V supply; the NeoPixel strip on a 5 V supply; lamps and solenoids on their own supplies. Every ground is tied together.

## The four driver circuits

Every connection is one of these four. (Simplified from your KiCad schematic — the full schematic is at the bottom.)

① Switch input — active-High

3.3 V→ hole switch→ FT232H pinDx / Cx→ 10 kΩ→ GND

Closing the hole switch pulls the pin to 3.3 V; the 10 kΩ holds it Low otherwise. Software reads "High" = pressed. The 7 gobble holes all wire to one pin (S23).

② Lamp driver — PN2222A (×16)

FT232H pinCx / Dx→ 1 kΩ→ PN2222Abase→ lamp→ lamp V+via J2

Pin High → transistor conducts → lamp lights. Emitter to GND. All score / indicator lamps use this, out through harness connector J2.

③ Solenoid driver — TIP120 + flyback (×2)

GPIO3 C0/C1→ 1 kΩ→ TIP120base→ solenoid coil→ solenoid V+fused

Higher-current TIP120 for the coils, with a 1N4004 across each coil to catch the flyback spike on release (fused via F1/F2). Coin-lock (C0) and win-lock (C1) only. Emitter to GND.

④ NeoPixel strip — WS2812b

GPIO4 D1SPI MOSI→ strip DIN

5 V→strip +5V GND→strip GND

Data only from GPIO4 D1 (MOSI), via the SPI1 / “5VDC” connector. Power the 150-pixel strip from the 5 V supply — never from USB.

## External power & how it connects to the board

Five power domains. Everything shares one common ground — tie the USB/logic ground and every supply's ground together, or nothing will read/switch correctly.

Supply | Voltage | Board connector | Powers
Mini-PC | USB 5 V | U1–U4 (USB) | FT232H board logic (via the USB hub)
Wall PSU | 3.3 V | J1 “3VDC” | the common side of every playfield switch
Wall PSU | 5 V | SPI1 “5VDC” | WS2812b strip (+5V); data comes from GPIO4 D1
Lamp PSU | V+ (lamp) | J2 harness | all score / indicator lamps (through PN2222A)
Solenoid PSU | V+ (coil) | solenoid conn | coin-lock & win-lock coils (through TIP120, fused F1/F2)

## The board, labeled

Top copper. Each FT232H socket (U1–U4) is silk-labeled with the serial that must go in it. Full pin-by-pin: SkillGame_GPIO_Map.html.

SkillGame PCB top copper with labeled FT232H sockets

Game board — sockets U1–U4 = GPIO1–GPIO4; power/LED/solenoid connectors at the edges.

## FT232H board pinout

Each of the four modules is this Adafruit FT232H breakout. D4–D7 / C0–C7 are the GPIO used here; D0–D3 are the SPI/MPSSE pins (only D1/MOSI is used, on GPIO4).

Adafruit FT232H pinout

## Full schematic (from KiCad)

Your actual SkillGame.kicad_sch, rendered. This is the source the driver circuits above are simplified from — open it in KiCad to zoom into any net.

Full SkillGame KiCad schematic

U1–U4 = the FT232H boards · SW0–SW27 with 10 kΩ pull-downs · Q1–Q6/Q9–Q18 PN2222A lamp drivers · Q7/Q8 TIP120 solenoid drivers · J1 3VDC · J2 lamp harness · SPI1 LED strip.

## Wiring checklist

- Serials first. Program each FT232H's serial to GPIO1…GPIO4 and seat it in the matching silk-labeled socket (U1–U4).
- Common ground. Tie the USB logic ground and the 3.3 V, 5 V, lamp, and solenoid grounds together.
- Switches to the input pins (each with its 10 kΩ pull-down); all 7 gobble holes parallel to one input (S23).
- Lamps to J2; solenoids to the TIP120 outputs — confirm the 1N4004 flyback and fuses are fitted before powering the coils.
- NeoPixel data to GPIO4 D1; power from the 5 V supply.

SkillGame wiring guide · pairs with SkillGame_GPIO_Map.html (pin map) and the Setup & Troubleshooting doc.

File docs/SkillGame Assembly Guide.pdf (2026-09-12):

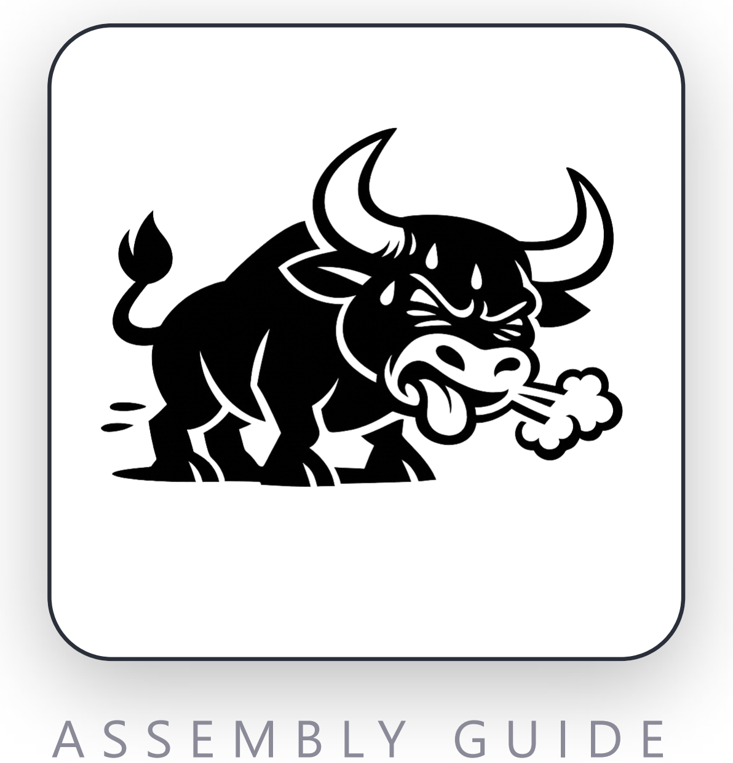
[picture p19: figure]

# SKILLGAME

A T R I B U T E T O T H E G A M E O F S K I L L

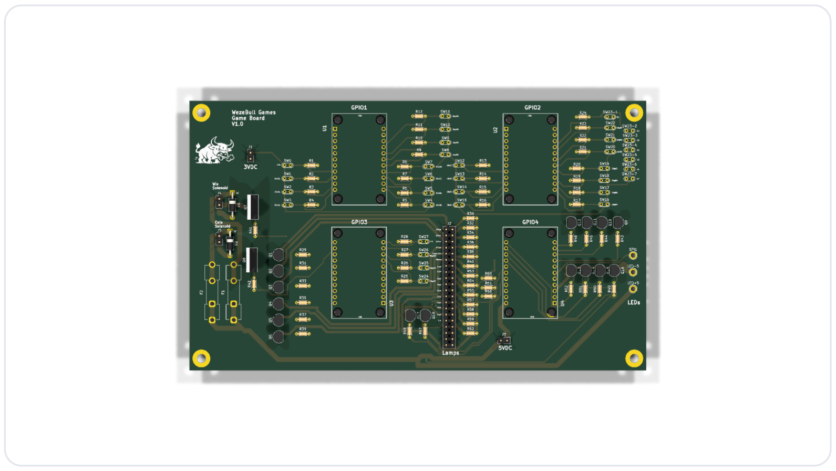
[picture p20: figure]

A L L H U F F · N O B U L L

WezeBull Games · build it once, build it right

# Parts list

E V E R Y T H I N G Y O U N E E D B E F O R E Y O U S TA R T

QTY | PART | WHAT IT'S FOR

THE BOARD
4 | Adafruit FT232H breakout | USB→GPIO controllers (U1–U4)
16 | PN2222A transistor (TO-92) | lamp / reel drivers
2 | TIP120 Darlington (TO-220) | solenoid drivers (Q7/Q8)
2 | 1N4004 diode | solenoid flyback (D1/D2)
28 | 10 kΩ resistor | switch pull-downs
16 | 1 kΩ resistor | transistor base
16 | 0 Ω jumper (or solder bridge) | lamp links R30–R62 — the #555 bulb self-limits
28 | 100 nF ceramic cap (0805 SMD) | C1–C28 · switch-input debounce/noise (back of board)
2 | 2.2 kΩ resistor | TIP120 base
4 5×20 mm fuses · 4 Keystone clips + 2
| inline holders | F1/F2 T2A (solenoids) · F3 T3.5A inline (5 V to J3) · F4 T5A inline (strip feed)
1 | 2×20 pin header (J2) | lamp / output connector
4 | 2-pin headers (J1/J3/J4/J5) | power in + solenoid out
~34 Arcade coin switch (85 mm wire
| actuator) | 28 inputs (S23 = 7 gobble) · coin trips the wire in the slot
1 | WS2812b LED strip, 150 px | attract / distract shows
20 #555 wedge LED bulb (6.3 V, non-
| polar) | 16 lamps + a 2nd bulb on 100/200/300/400 (double bright)
20 | #555 / T10 wedge socket (twist-lock) | one per bulb; solder its leads to the J2 lamp lines
2 | SparkFun Solenoid - 5V (Small) | coin-lock + winner-lock

THE SYSTEM

### 1 PELADN Ryzen 5 5600H mini-PC (16

| GB / 512 GB) | runs SkillGame

### 1 QQU 15.6" portable touchscreen

| (with stand) | the display · 1080P IPS/HDR touch
1 | 4-port USB 2.0 hub | one port per FT232H
1 | 3.3 V wall adapter | switch / GPIO logic (J1)

1 5 V wall adapter — BTF-LIGHTING 5 V 10 A 50 W (ETL)

the whole 5 V system — split to J3 (F3, board) + strip (F4); ~6.3 A worst, 10 A leaves headroom
1 | 2-way terminal block / Wago 221 | splits the 5 V brick into the F3 (board) and F4 (strip) branches; commons the grounds

T O O L S
- Soldering iron + solder
- Flush cutters
- Small screwdriver
- Multimeter
- Wire + crimp/ferrules

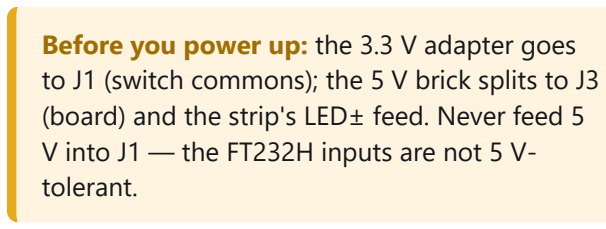
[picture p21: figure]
tolerant.

| | Before you power up: the 3.3 V adapter goes to J1 (switch commons); the 5 V brick splits to J3 (board) and the strip's LED± feed. Never feed 5 V into J1 — the FT232H inputs are not 5 V-

SkillGame Assembly Guide · page 1

## 1 Meet the four boards

Adafruit FT232H — one per GPIO bank

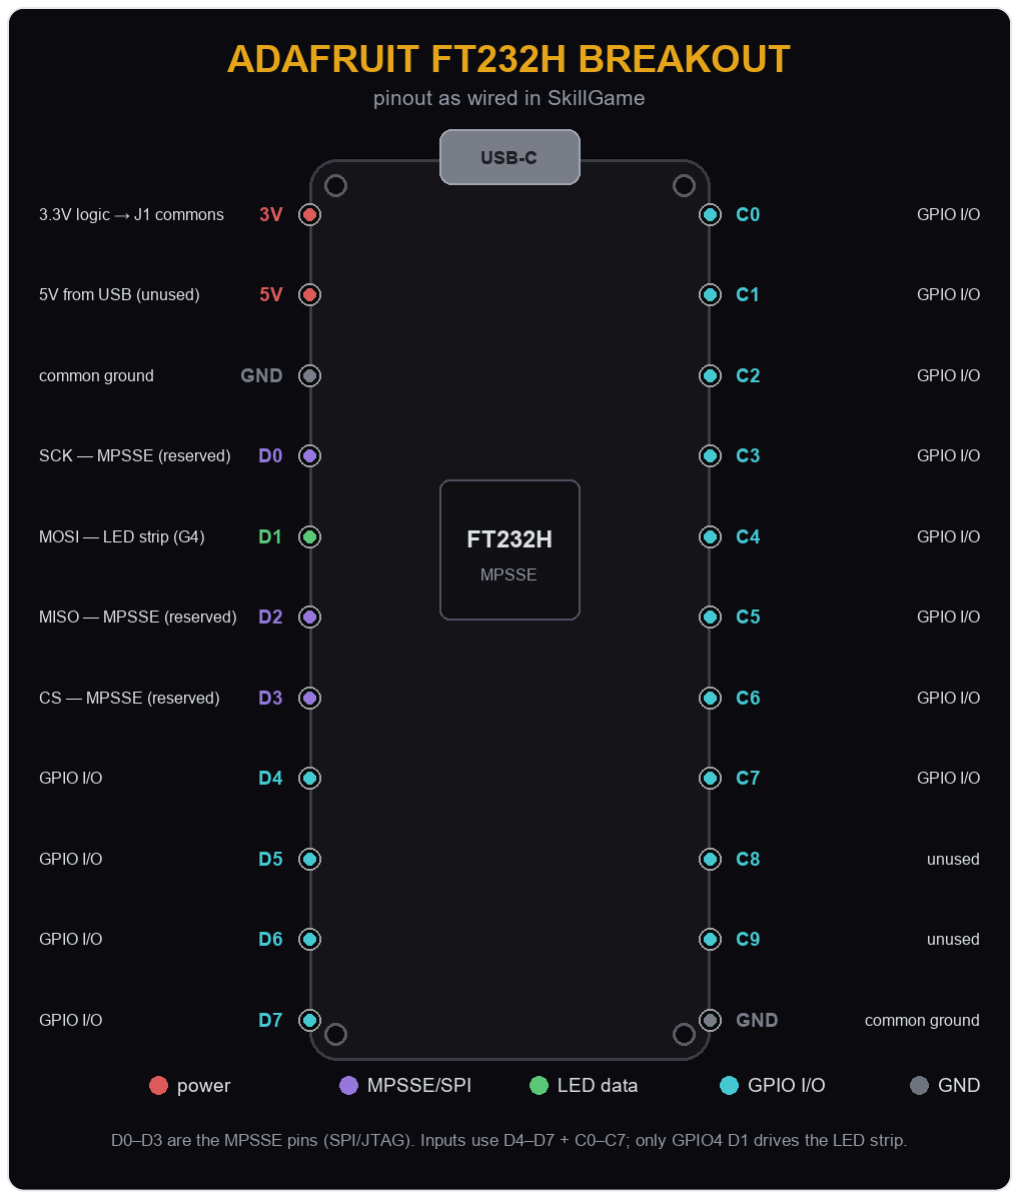
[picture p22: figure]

Four Adafruit FT232H breakouts, each in MPSSE mode over USB-C — the app talks to all four through the USB hub.
GPIO1 / GPIO2 read switches; GPIO3 reads the top rows + tilt and drives the 100–400 reels, Winner, Game-Over and the two coil lines; GPIO4 drives the 10–90 + Tilt lamps and clocks the LED strip.
Pins D0–D3 are reserved (SPI/JTAG) — all switch/lamp I/O lives on D4–D7 and C0–C7. Only GPIO4's D1 is used, for the LED strip.
Program each board with a unique FTDI serial (GPIO1–GPIO4) so the software binds the right board to the right job no matter which USB port it lands on.

The FT232H's own 3 V / 5 V pins stay unconnected — the boards are USB-powered.
SkillGame Assembly Guide

2

## Solder the drivers

resistors, then transistors — lowest parts first

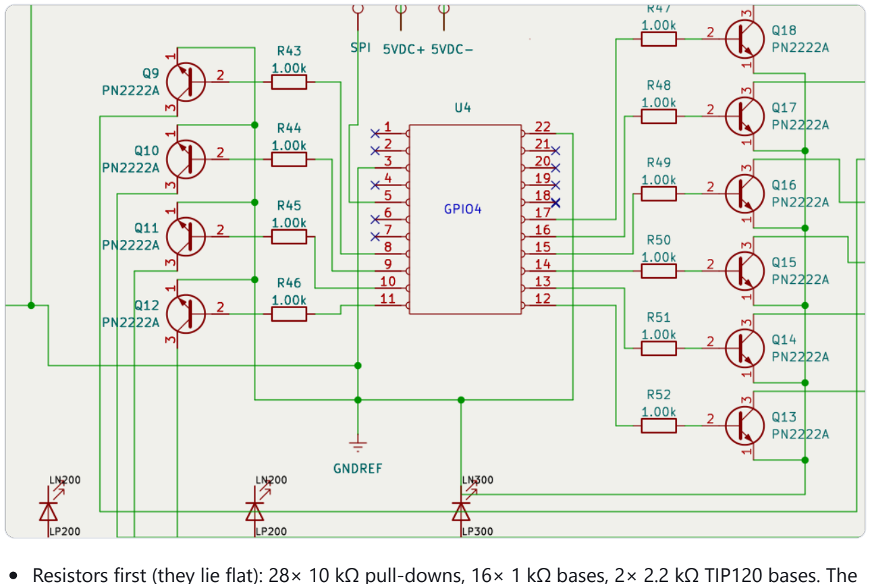
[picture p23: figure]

Resistors first (they lie flat): 28× 10 kΩ pull-downs, 16× 1 kΩ bases, 2× 2.2 kΩ TIP120 bases. The 16 lamp positions (R30–R62) are 0 Ω links — a jumper wire or solder bridge, since the #555 bulbs self-limit.
Then the 16 PN2222A transistors (TO-92) — mind the flat/rounded face matches the silk.
Keep leads short; flush-cut the backs.

SkillGame Assembly Guide

3

## Solenoid drivers + fuses

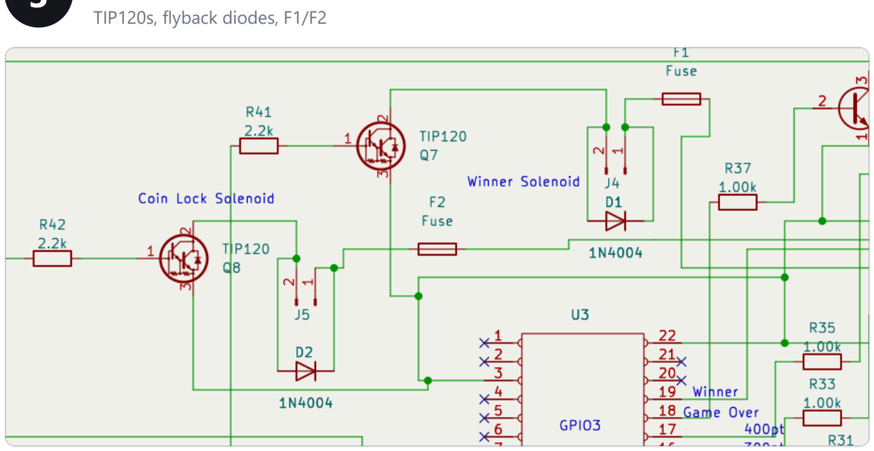
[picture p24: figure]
TIP120s, flyback diodes, F1/F2

⚠ TIP120 orientation: collector goes to the coil, emitter to ground. If you are using an older board revision, cross the collector (middle/tab) and emitter (right) leads on Q7 & Q8 — a straight insert wires them backwards and the coils won't switch. The current KiCad files already have this fixed.

Fit the two TIP120s (TO-220) and the 1N4004 flyback diodes — band matches the silk. Install the Keystone 3517 clips and drop in the fuses (see next page).

SkillGame Assembly Guide

## 3b Fuse the solenoids

F1 / F2 — one per coil, on the board

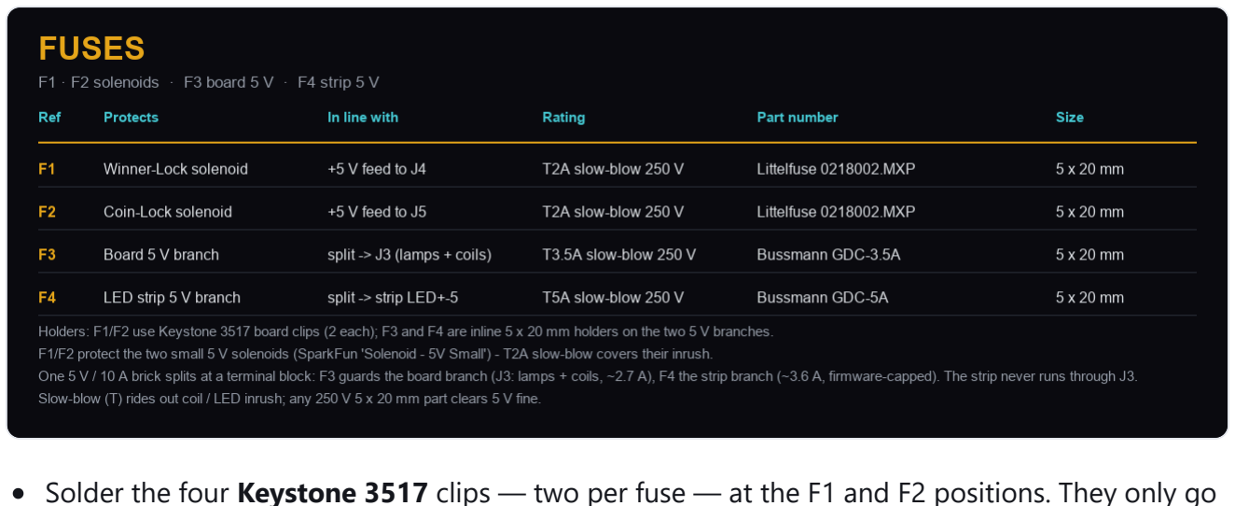
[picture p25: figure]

Solder the four Keystone 3517 clips — two per fuse — at the F1 and F2 positions. They only go one way; the fuse snaps in across the pair.
Drop in the fuses: F1 guards the Winner-Lock coil (J4), F2 the Coin-Lock coil (J5). Both are T2A slow-blow, 5×20 mm (Littelfuse 0218002.MXP).
Slow-blow (T) rides out the coil's turn-on surge; it opens only on a real short. Any 250 V 5×20 mm part is fine on the 5 V rail.

SkillGame Assembly Guide

## 3c The inline 5 V fuses

one brick, split → F3 (board) + F4 (strip)

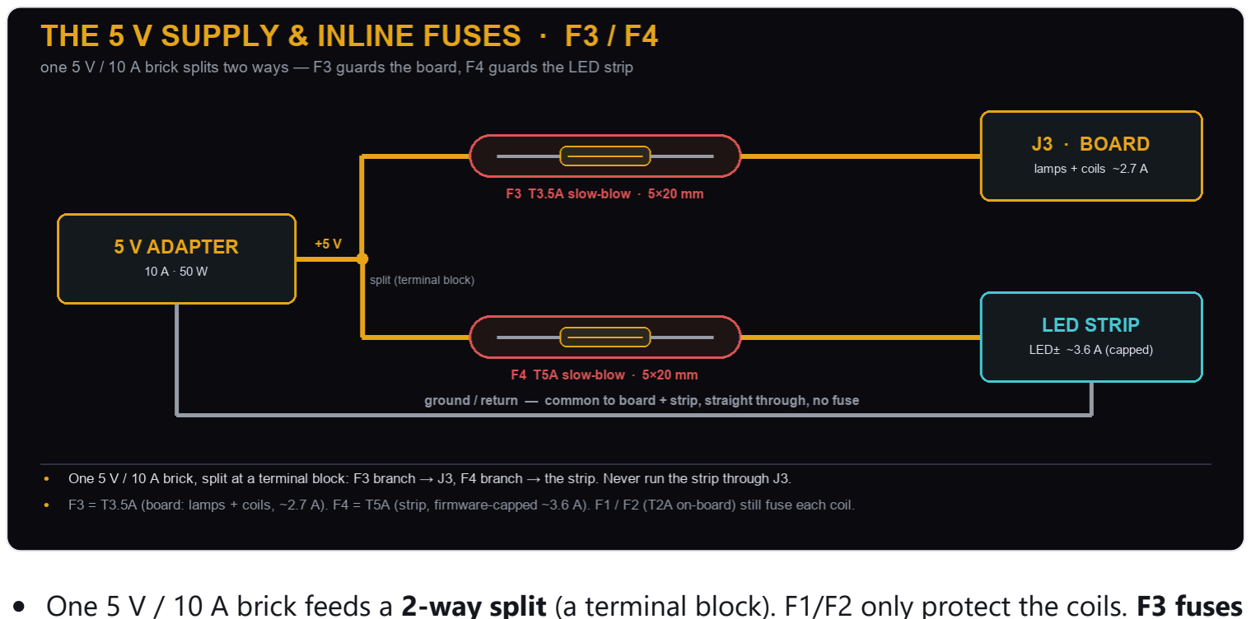
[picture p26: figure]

One 5 V / 10 A brick feeds a 2-way split (a terminal block). F1/F2 only protect the coils. F3 fuses the board branch — J3, lamps + coils, ~2.7 A worst. The strip is the other branch (see step 6c), fused by F4 — never through J3, because its draw is far larger.
Neither is on the PCB: from the split, run the board's +5 V through the F3 inline holder to J3, and the strip's +5 V through the F4 inline holder (uxcell 18 AWG, screw-terminal). Leave the ground/return whole and common.
Fit F3 = T3.5A (Bussmann GDC-3.5A) on the board branch and F4 = T5A (GDC-5A) on the strip branch — both slow-blow, 5×20 mm.

Rule of thumb: a fuse ≈ steady current + inrush headroom, and always below what the wiring can carry. T3.5A suits the board branch (~2.7 A); T5A suits the strip branch (~3.6 A capped).

SkillGame Assembly Guide

## 4 Headers & sockets

J1–J5, the J2 lamp header, and the 4 FT232H sockets

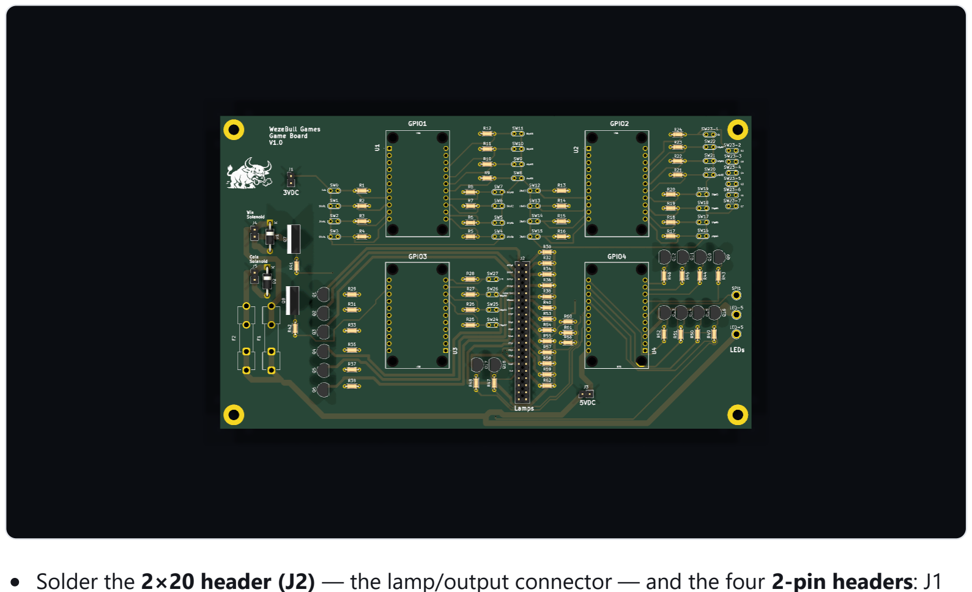
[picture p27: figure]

Solder the 2×20 header (J2) — the lamp/output connector — and the four 2-pin headers: J1 (3.3 V in), J3 (5 V in), J4 (Winner-Lock), J5 (Coin-Lock).
Tack one pin first, check the header sits flat and square, then solder the rest — a skewed 40-pin header is miserable to fix.
Fit the four FT232H sockets with even spacing so the boards sit flat and don't touch. The footprints already have clearance; don't skew them.
Note which socket is GPIO1–GPIO4 (silk) — it must match the serial you programmed into each board.

SkillGame Assembly Guide

## 5 Wire the switches

28 inputs → J1 commons, pulled to ground

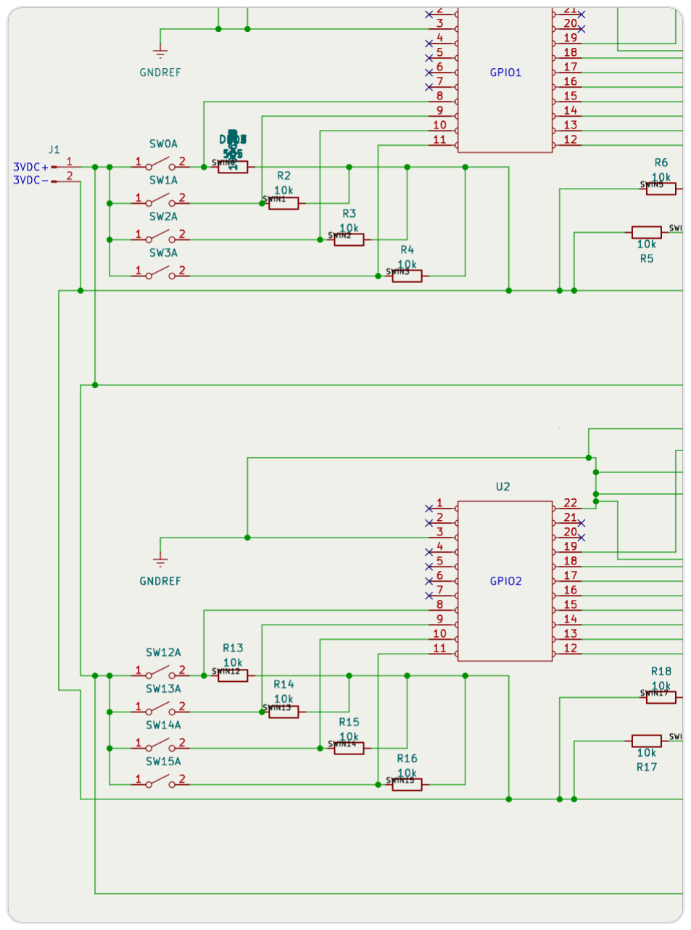
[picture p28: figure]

28 inputs across GPIO1–3 (D4–D7, C0–C7). One side of every playfield switch ties to the shared J1 3.3 V common; the other side goes to that switch's FT232H input pin.
An on-board 10 kΩ pull-down holds each input LOW; closing the switch pulls it to 3.3 V (a real HIGH) and the software reads the hit.
Keep the common at 3.3 V — never 5 V. The FT232H inputs are not 5 V-tolerant; 5 V on an input can kill the chip.
The 7 gobble holes all report as one input (S23): wire their switches in parallel so any of them trips it.
Run it as a harness (see the last pages): one 3.3 V bus wire daisy-chained to every switch, plus one signal wire per switch back to the board.

SkillGame Assembly Guide

## 5b Fit the input caps

28× 100 nF on the board's back — debounce & noise

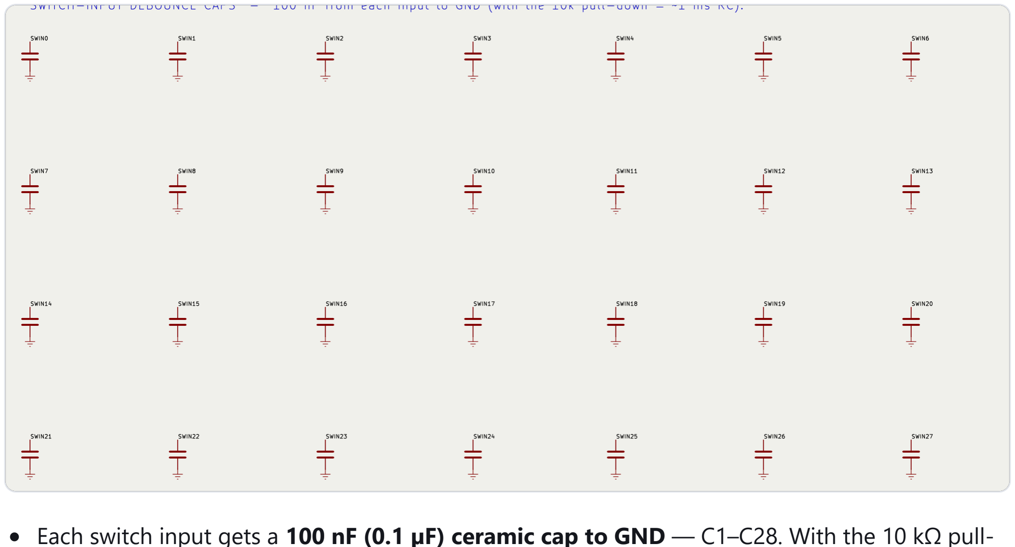
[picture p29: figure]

Each switch input gets a 100 nF (0.1 µF) ceramic cap to GND — C1–C28. With the 10 kΩ pull-down it forms a ~1 ms RC filter that kills contact chatter and noise picked up on the long playfield leads.
They're SMD 0805 on the back of the board, one tucked next to each pull-down (GND pad on the ground pour, the other to the input). Solder them last.
Optional but recommended — the game still works without them (the software also debounces), but they make the long switch runs far more reliable.

SkillGame Assembly Guide

6

## The score lamps

off-board #555 wedge LED bulbs on J2

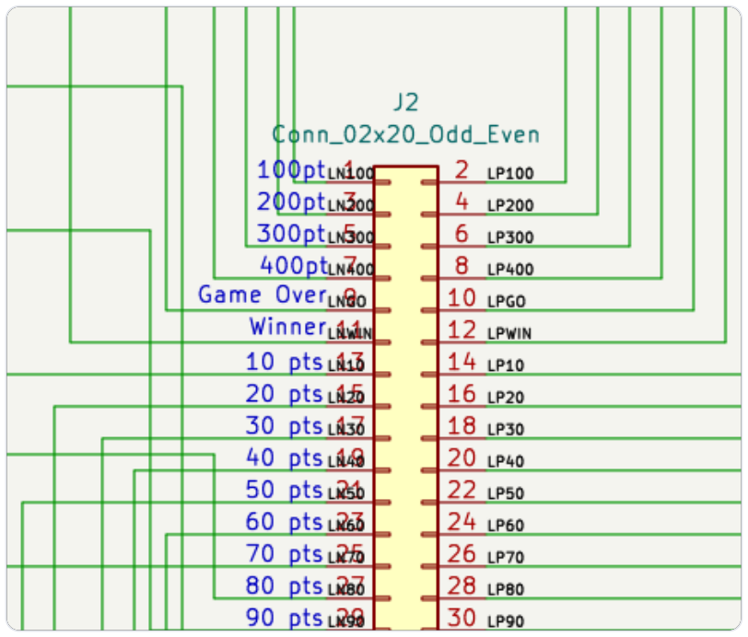
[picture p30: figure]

Every score lamp — the tens 10–90, the reels 100–400, and Winner / Game-Over / Tilt — is a #555 wedge LED bulb in a twist-lock socket, off the board.
Each bulb plugs across one J2 pin pair. The odd pin (left, labelled with the lamp name) is switched by the transistor; the even pin (right) is +5 V through that lamp's 0 Ω link. The labels on J2 tell you which pair is which lamp.
Solder the socket's two leads to that pin pair. The #555 bulbs are non-polar, so which lead goes

Wire it as a harness (see the last pages): a 2×20 plug on J2, fanning out to all the sockets, is far tidier

SkillGame Assembly Guide

## 6b Double up the big holes

100 / 200 / 300 / 400 — two bulbs each

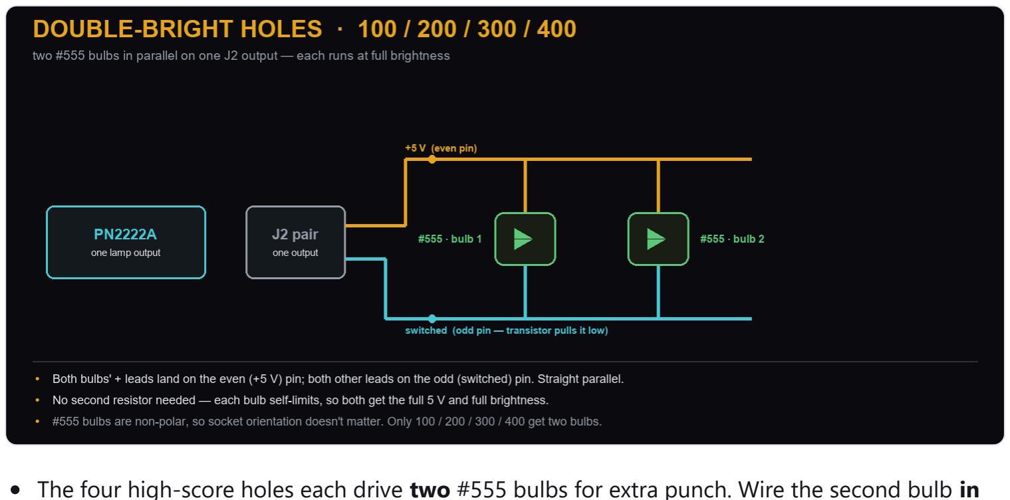
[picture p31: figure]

The four high-score holes each drive two #555 bulbs for extra punch. Wire the second bulb in parallel on the same J2 pair as the first.
Both bulbs' + leads land on the even (+5 V) pin; both other leads on the odd (switched) pin. No extra resistor — each bulb self-limits, so both run at full brightness. The transistor easily drives two.

SkillGame Assembly Guide

## 6c Coils & the LED strip

solenoids off J4 / J5, strip off SPI

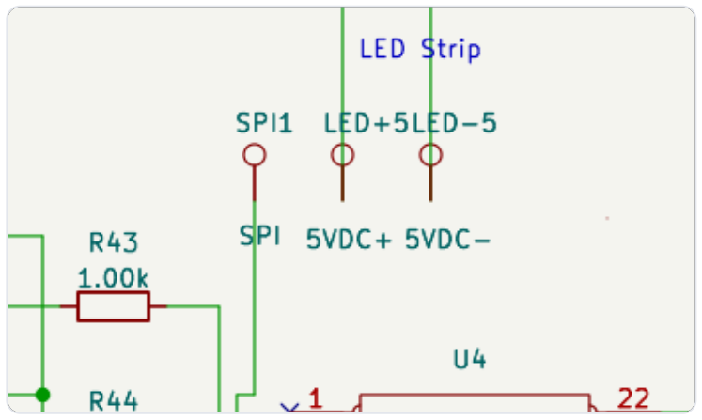
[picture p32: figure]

Coin-Lock → J5, Winner-Lock → J4. These are the fused (F1/F2), TIP120-driven 5 V coils — keep the flyback diode across each coil.
They are spring-return coils: at rest the plunger is pushed OUT (blocking a coin) with no power. The software fires each as a brief pulse — it retracts to drop the coin, then springs back. They are never held energized (intermittent-duty), so mount each with the plunger blocking its coin path at rest.
LED strip data → GPIO4's D1 (SPI MOSI). Data is one wire plus a common ground.
Power the strip on its own branch off the 5 V brick (LED+5 / LED−5 through fuse F4, T5A inline), not through J3, so its heavy draw can't sag the lamp/logic rail. Tie all grounds common. Why the separate branch: 150 px at full white is ~9 A. The firmware caps the strip to ~40 % brightness (LightFunctions.MaxBrightness), holding a worst-case frame under ~3.6 A; with the board's ~2.7 A that's ~6.3 A total, which the 10 A brick covers.

SkillGame Assembly Guide

## 7 Hook up the system

PC · hub · monitor · power

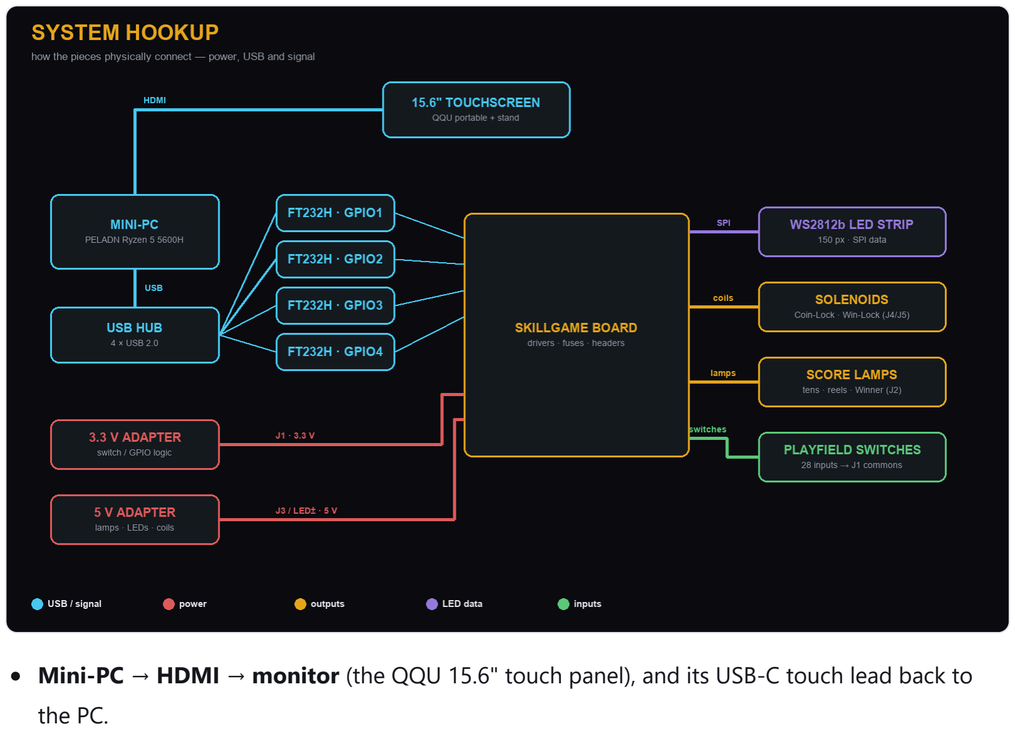
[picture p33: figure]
the PC.

Mini-PC → HDMI → monitor (the QQU 15.6" touch panel), and its USB-C touch lead back to

Mini-PC → USB hub → the four FT232H boards — one hub port per board.
3.3 V adapter → J1 (switch commons). One 5 V brick → terminal-block split: the F3 branch → J3 (board: lamps + coils), the F4 branch → the strip's LED± feed. Separate branches so the strip can't sag the board rail.
Tie every ground together — the 3.3 V return, the 5 V return, the LED strip and the boards all share one common ground, or nothing reads right.
Double-check J1 is 3.3 V and J3 is 5 V before powering on. They are not interchangeable.

SkillGame Assembly Guide

8

## Power on & self-test

let the software check your wiring
Launch SkillGame, open Diagnostics, and run Self-Test — it lights every lamp, pulses the coils and sweeps the LED strip.
Use the Switch Monitor to press each playfield switch and confirm it registers (and clears).
Any input stuck HIGH shows as a fault ring — check that switch's wiring and pull-down. Green badge on Diagnostics = all boards present and healthy. You're done. ALL HUFF ·

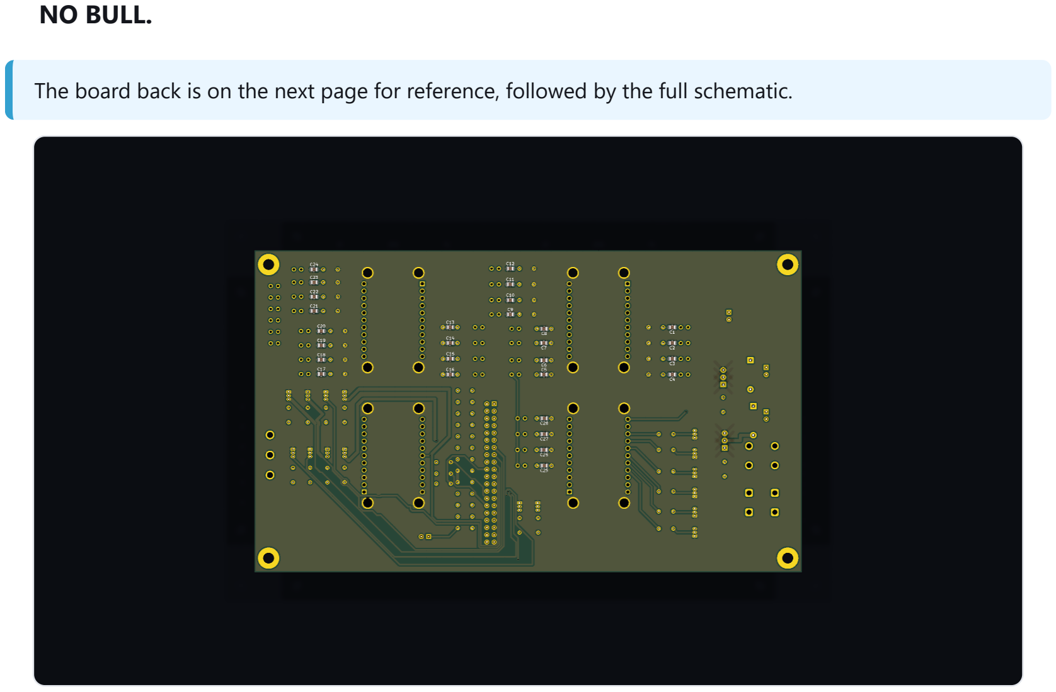
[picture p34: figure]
NO BULL.

The board back is on the next page for reference, followed by the full schematic.

SkillGame Assembly Guide

# Wiring reference

W H E R E E V E R Y W I R E L A N D S O N T H E B O A R D

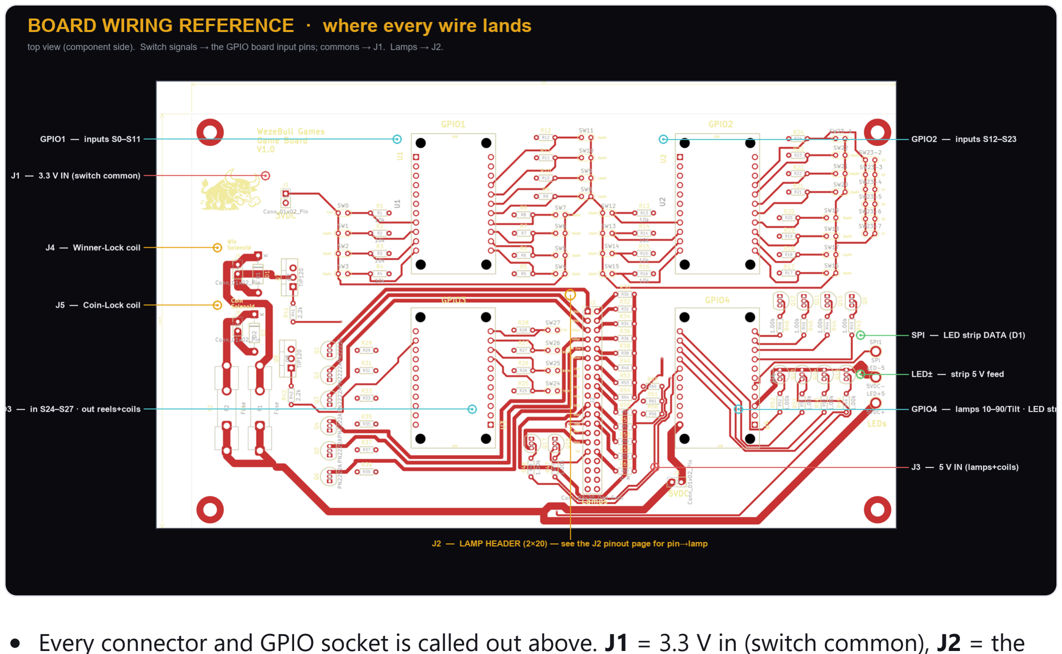
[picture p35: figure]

Every connector and GPIO socket is called out above. J1 = 3.3 V in (switch common), J2 = the 2×20 lamp header, J3 = 5 V in, J4/J5 = the two coils, SPI + LED± = the LED strip.
Switch signals land on the GPIO board input pins (next page); lamp wires land on J2 (pin→lamp map is on the J2 page).

SkillGame Assembly Guide

## IN Switch-input pin map

which pin every switch wire goes to

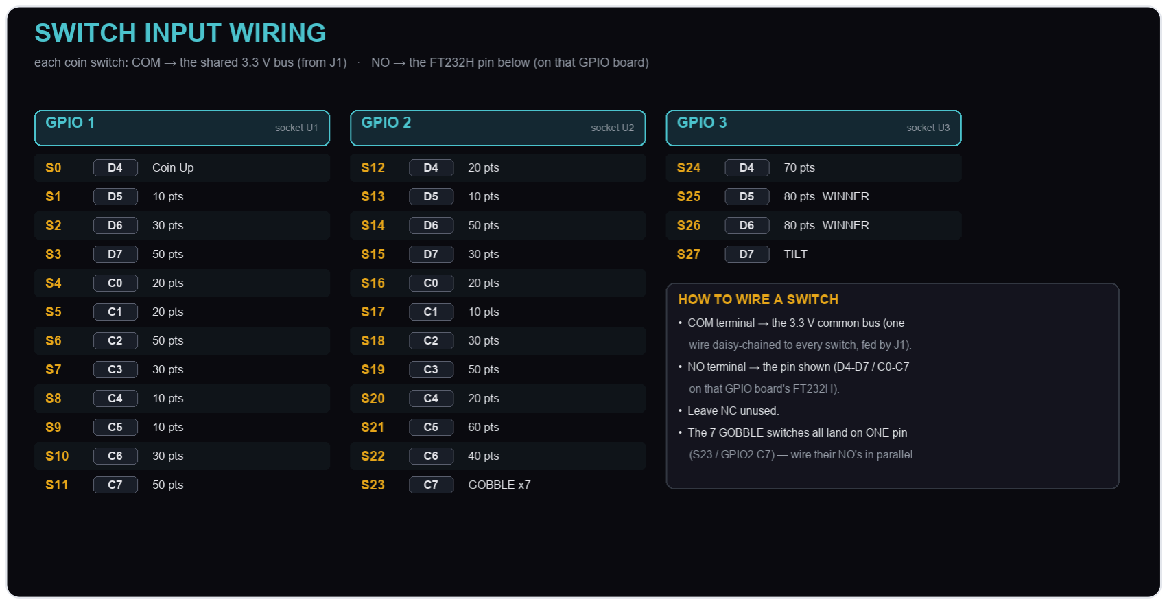
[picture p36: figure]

Each coin switch is a plain SPDT: COM → the 3.3 V common bus (fed by J1), NO → the FT232H pin shown. NC is unused. The 7 gobble switches all wire in parallel onto the one S23 pin (GPIO2 · C7).

The switch: an arcade coin switch with an 85 mm straight wire actuator (SPDT, ~$3.99 ea; ~$2 in 10-packs). The long wire pokes up through a playfield slot and the rolling coin trips it — light touch, body hidden under the playfield. Wires like any SPDT switch (COM + NO), so no board changes. Same style

SkillGame Assembly Guide

# Full schematic

R E F E R E N C E

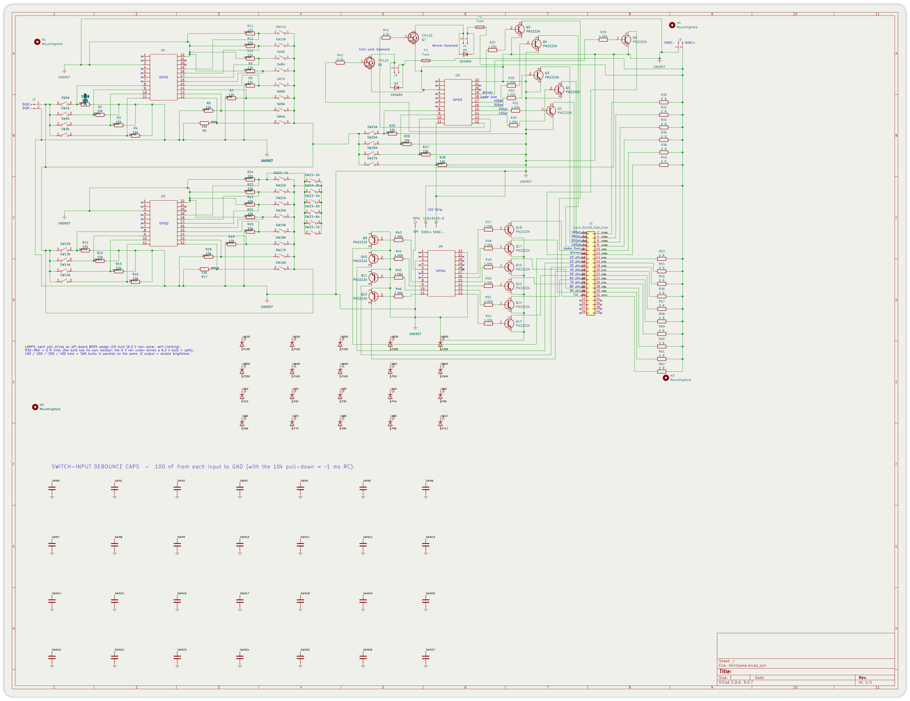
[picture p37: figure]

SkillGame · WezeBull Games

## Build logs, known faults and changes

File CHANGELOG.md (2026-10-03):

# SkillGame changelog

Every released version and what changed. The in-app updater (Service → Check for Updates)
shows these notes before installing. Cut a new release with `tools/publish-update.ps1`.

## v1.1.0 — 2026-10-03
- **12 UI themes** (Settings → Theme): Classy, Fun, Plain, Blackout, Vintage, Maple, Midnight, Synthwave, Lava, Circuit, Galaxy, Ruby — each reskins the whole UI and the playfield art.
- **Original wood playfield** replaces the Bally artwork (same rail/hole layout, so coin paths are unchanged).
- **Updater hardened** — unzip + copy + relaunch only; no PC reboot and no temp script (that pattern tripped endpoint security).
- **Install any version** — the updater lists every release and installs forward or back, with the latest tagged; auto-checks on boot + every 6 h.
- **Diagnostics** — each board's hardware tests are disabled when that board is missing (GPIO3 = reels/Winner/Game-Over + lock coils, GPIO4 = 10-90 lamps/Tilt + LED strip).
- Marquee is warm maple instead of the rainbow; "Roll · Climb · Win" subtitle; fixed the boards-missing tombstone clipping on Diagnostics.

## v1.0.1 — 2026-10-01
**New**
- In-app software updates: check the WezeBull server, see what changed, install with one tap; the machine swaps the files and restarts itself.

**Fixes & improvements**
- Solenoids pulse instead of being held on (no coil overheat); spring-return gate — plunger out blocks a coin, a pulse drops it.
- LED strip brightness capped so a full-white frame can't brown out the 5 V supply.
- Power simplified to one 5 V / 10 A brick, split into two fused branches (F3 board, F4 strip).
- Board design rules gated at real fab minimums (DRC clean).

## v1.0.0
- Initial build: Game Status, Diagnostics, Audits, Service, interactive Schematic; 4× FT232H hardware layer; demo/attract mode; unit-tested game core.

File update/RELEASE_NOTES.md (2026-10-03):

# SkillGame v1.1.0

SkillGame v1.1.0

- 12 UI themes (Settings -> Theme) - each reskins the whole app AND the playfield.
- Original wood playfield replaces the old board (same layout).
- Updater: install ANY version, forward or back; unzip + copy + relaunch, no PC reboot.
- Diagnostics: a board's hardware tests are disabled when that board is missing.
- Warm maple marquee (no rainbow); fixed the boards-missing tombstone clipping.

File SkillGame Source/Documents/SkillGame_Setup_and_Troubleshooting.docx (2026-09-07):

SkillGame

Build, Theory of Operation & Service Manual

A modern recreation of Bally's 1955 Skill-Roll nickel-flip game, run from a Windows mini-PC over four FT232H USB boards. This manual covers the hardware, first-time setup, wiring, how the software is put together and how it flows, what every class and function does, what every LED pattern looks like, what every diagnostics control does, the audit system, troubleshooting, a bill of materials, the full pin map, schematic/PCB notes, and a list of ideas for later.

# 1. Theory of operation

The player works the levers to flip a nickel up the inclined playfield. On each row the nickel settles into a scoring hole; landing a hole adds its points, lights the matching score lamps, and advances a level. Reaching a top-row (Row 8) hole wins — the Winner lamp lights and the win-lock solenoid fires. A gobble hole or a tilt ends the game.

The mini-PC is the whole game controller. There is no separate microcontroller — the four FT232H USB breakouts simply give the PC direct GPIO/SPI pins. Two boards read the playfield switches, one mixes a few inputs with the score-reel / solenoid outputs, and one drives the tens lamps plus a WS2812b show strip. The program runs a tight loop: read the switch pins, decide what each change means, update the score/level, drive the lamps and sounds, and mirror everything onto the on-screen diagnostics panel. It also keeps a permanent audit log (games, play time, per-switch hits) on disk.

# 2. Hardware

- Windows mini-PC (16 GB RAM, SSD) - runs the game and the diagnostics/audits screen.
- 4 x Adafruit FT232H USB breakouts, identified by FTDI serial number GPIO1-GPIO4 (not by which socket they sit in).
- 3.3 V supply for switch inputs; 5 V supply for the WS2812b strip; separate lamp and solenoid supplies; one common ground.
- Playfield switches, score lamps, coin-lock & win-lock solenoids, and a 150-pixel WS2812b strip.

Board | Role
GPIO1 (U1) | 12 switch inputs - Coin Up + Rows 1-3
GPIO2 (U2) | 12 switch inputs - Rows 3-6 + shared gobble switch
GPIO3 (U3) | 4 switch inputs (Rows 7-8, Tilt) + 8 outputs (reels, Game Over, Winner, solenoids)
GPIO4 (U4) | 10 tens-lamp outputs + WS2812b data on D1 (SPI MOSI)

# 3. Software architecture - the pieces

Written in C# on .NET 8 (Windows Forms). It is split by responsibility so the game rules are independent of the hardware and of the on-screen UI. That separation is what lets the rules be unit-tested and, later, drive a second (in-cabinet) display.

File / class | What it is responsible for
Program.cs | Entry point. Starts logging and runs the form.
SkillGameForm.cs (+ .Designer) | The diagnostics/audits window: tabs, buttons, status boxes. Also implements IGameView so the rules can push status to it.
SkillGameForm.Audits.cs | Builds the read-only Audits tab in code and refreshes it.
SkillGameForm.Hardware.cs | Builds the Hardware Status strip (GPIO1-4 board presence) at the bottom of the Diagnostics tab, plus the POST readout and the View Log / Wiring Test buttons.
SkillGameForm.Setup.cs | Builds the OPERATOR SETUP panel on the Settings tab and reads/writes OperatorSettings.
SkillGameForm.Extras.cs | Fills the Game Status page (clock, high score, session tally, quiet status) and the Settings page (Machine Info, Backup Audits, SKILLGAME banner); colour-codes the diagnostics buttons by section.
SkillGameForm.Tooltips.cs | Hover help for every interactive control on the form.
OperatorSettings.cs | Operator-tunable settings (count-up speed, tilt on/off, quiet hours) saved to operator_settings.json; loaded at startup and pushed into the live subsystems.
LogViewerForm.cs | Pop-up that shows the tail of skillgame.log on screen (REFRESH re-reads it).
WiringTestForm.cs | The guided wiring test window - walks the switch matrix one switch at a time and confirms each is wired to the expected pin.
IoMapForm.cs / PinActivity.cs / PinCatalog.cs | The live I/O activity map (floating pin display) plus the shared pin-state hub it listens to and the pin directory (inputs from SwitchMap, outputs from LampController) it draws.
GlassButton.cs | The rounded, glass-look button used across the whole form (owner-drawn: gradient body, soft top sheen, lighter border, hover/press states).
GameInterfaces.cs | The small contracts the rules depend on: IGameView, IAudioSink, ILampSink, IAuditSink, ILedSink.
GameEngine.cs | The game RULES only - score, level, coin/hit/gobble/tilt/winner. No WinForms or hardware types, so it is fully testable.
GPIOFunctions.cs / .Switches.cs | The coordinator + the generic switch-polling loop and dispatcher.
SwitchMap.cs | The switch matrix as data - one row per switch (board, pin, points, level, kind).
FtHardware.cs | Finds the four FT232H by serial, opens the pins, brings up the SPI strip, exposes the pin maps.
LampController.cs | Physical lamp/solenoid output: the score count-up plus the chase / inside-out / flash lamp patterns.
LedEffects.cs / LightFunctions.cs | WS2812b strip: the effect wrappers and the animation library (14 patterns).
AudioFunctions.cs | Sound playback and Windows volume control (NAudio).
AuditStore.cs | The machine's permanent 'books' - games, play time, per-switch hits; JSON on disk.
Log.cs | A tiny always-on file logger.
LayoutScaler.cs | Scales the whole form to fill any screen resolution.
SkillGame.Tests | xUnit tests for the game rules + operator settings + audio safety (27 tests).

# 4. How the code flows - a switch press, start to finish

In plain terms, here is the life of one nickel drop:

1. 1. App start (Program.Main): set up logging, then show the form.
2. 2. Form constructor: build the window, load the saved audits, build the Audits tab and the Diagnostics Hardware-Status strip, snapshot the layout for scaling, go full screen, and start a background loop that keeps the on-screen volume readout current.
3. 3. Form Load: pre-select the combo boxes, play the startup sound, then create GPIOFunctions and call InitializeGPIO().
4. 4. InitializeGPIO(): FtHardware.Initialize() finds the four FT232H by serial number, opens every input/output pin, and starts the WS2812b strip. It then builds the LampController, LedEffects, and GameEngine (handing the engine the audit log), applies the saved operator settings (count-up speed, tilt on/off), calls StartGPIO(), and runs a power-on self test (POST) that flashes the lamps + strip and records PASS/FAIL. If fewer than four boards are found it pops a clear 'Hardware Not Ready' message instead of crashing.
5. 5. StartGPIO(): launches one background polling task per input board.
6. 6. PollBoard() (loops forever until shutdown): reads every input pin each pass; when a pin's value changes since last pass, it calls OnSwitch(board, pin, high).
7. 7. OnSwitch(): looks the pin up in SwitchMap. If the Game Status tab is active it dispatches by switch kind to the rules - Coin, Hit, Gobble, or Tilt. If the Diagnostics tab is active it instead ticks that switch's checkbox so you can test wiring.
8. 8. GameEngine.Hit(): if the ball is on that switch's row, it records the hit in the audits, plays the point sound, adds the points, tells the LampController to count up to the new total, and advances the level (lighting the Winner lamp on a top-row hole).
9. 9. LampController.TallyScore(): runs the count-up animation - the tens lamps walk 10, 20, 30 ... up to the new total - and sets the hundreds reels.
10. 10. Back on screen: the engine calls the form (through IGameView) to update the Score / Level / Last Switch / Status boxes, safely from the background thread.
11. 11. Audits: AuditStore bumps its counters and saves the JSON at game boundaries; the Audits tab shows the running totals.
12. 12. Shutdown (form closing): the polling loops are cancelled, the hardware is released, and the audits are saved one last time.

# 5. What every function does

## GameEngine - the rules

Function | What it does
Coin(high) | Coin Up (S0). If no game is running it clears the board, then arms a new game at Level 1 and starts the audit game timer.
Hit(def, high) | A scoring hole. Ignored unless the ball is on that switch's row. Records the hit, plays the '<points> pts' sound, adds the points, drives the lamps (a big hit of 50+ fires a crazy flourish, otherwise a normal count-up), advances the level, and (on a Row-8 hole) declares a winner.
Gobble(high) | Gobble hole (S23). Plays 'Game Over', lights the Game Over lamp, ends the game, and closes the audit timer.
Tilt(high) | Tilt (S27). Lights the Tilt and Game Over lamps, ends the game, closes the audit timer.
ClearGame() | Resets score and level to zero and clears all score lamps.

## LampController - physical lamps & solenoids

Function | What it does
TallyScore(value) | The count-up: lights the tens lamps one at a time (10, 20, ... ) up to the new score, then sets the correct hundreds reel. Passing 0 clears everything. Starting it cancels any running lamp pattern.
SetLamp(name, on) | Turns a single named lamp/solenoid on or off (used by the diagnostics buttons). 'All' lights every lamp; 'All' off clears everything.
Winner() | Lights the Winner lamp and fires the win-lock solenoid.
ChasePattern() | A single lit lamp chases left-to-right along the tens (10 -> 90), then the hundreds (100 -> 400), repeating.
InsideOutPattern() | Lamps bloom outward from the centre of the backglass (50 on the tens row, 200/300 on the hundreds) to the ends, then shrink back.
SweepBounce() | A single lit lamp sweeps 10 -> 90 then bounces back 90 -> 10, repeating (a scanner across the tens row).
Cascade() | The tens fill up 10 -> 90 (each stays lit), then the hundreds tick over 100 -> 400 like a score reel; hold, clear, repeat.
FlashAll() | All score lamps flash on and off together.
Flourish(finalScore) | Big-hit celebration: rapid all-flash blinks + a fast double chase, then settle back onto the real score.
StopLampPattern() | Cancels any running pattern and clears the lamps.

## GPIOFunctions - coordinator & polling

Function | What it does
InitializeGPIO() | Brings up the hardware, builds the output/effect/engine layers, and starts polling. Shows a friendly message (not a crash) if the boards are missing.
StartGPIO() / PollBoard() | Launches and runs the background loops that read the switches and report changes.
OnSwitch(board, pin, high) | Turns a raw pin change into either a game action or a diagnostics checkbox tick.
StopGPIO() | Stops the polling loops cleanly at shutdown.
Lamp/LED/pattern delegations | Thin pass-throughs the diagnostics buttons call (CancelLights, SolidColor, StartLampChase, etc.); all null-safe so a no-hardware session never crashes.

## FtHardware / AudioFunctions / AuditStore / Log / LayoutScaler

Function | What it does
FtHardware.Initialize() | Enumerates the FT232H, matches each by serial to GPIO1-4, opens the input and output pins, and starts the WS2812b strip on GPIO4's SPI. Throws a clear message if a board is missing.
AudioFunctions.PlaySound / PlaySettingsSound / PlayThemeMusic / PlayStartup | Play a point/effect/menu/theme/startup sound from the sound package folders.
AudioFunctions.GetMasterVolume / SetMasterVolumeUp / Down / MuteVolume | Read and change the Windows master volume for the on-screen volume controls.
AuditStore.Load / Save | Read/write the audit JSON next to the exe.
AuditStore.GameStarted / GameEnded / Won / SwitchHit | The counters the rules call; GameStarted/Ended also track total play time.
Log.Info / Log.Error | Append a timestamped line to the log file (never throws).
LayoutScaler.Record / Apply | Snapshot the design layout once, then rescale every control + font to the current window size.

# 6. LED strip patterns - what each one looks like

Fourteen effects live in LightFunctions. Each has two forms: the base version runs continuously (used for the short 'Distract' burst when a high-value hole is hit), and an '...Attract' version that plays a fixed sequence and then clears (used by the idle Attract-mode cycle).

Pattern | What you see on the strip
Marquee | Theater-style running lights - lit segments march along the strip like a movie marquee.
Rainbow Wave | A full rainbow spread across the strip that scrolls, so the colors flow along like a wave.
Comet | A bright head streaks along leaving a fading tail behind it.
Breathe | The whole strip fades smoothly up to full and back down in a sine 'breathing' rhythm, in one color.
Crazy Strobe | Rapid, hard flashes alternating groups of pixels between yellow and blue - a chaotic strobe.
Plasma Wave | Soft blobs of color morph and drift along the strip like a plasma field.
Meteor Rain | Meteors shoot across the strip leaving decaying trails, with a little random sparkle.
Sparkle | Random individual pixels twinkle on and fade, like glitter or stars.
Knight Rider | A single bright block sweeps end to end (the KITT / Cylon scanner eye) with a short trail.
Bouncing Balls | Several colored balls of light bounce along the strip with gravity-like motion.
Lightning | Sudden bright flashes at random positions and intervals, like lightning strikes.
Confetti | Random bursts of colored pixels pop and fade all over the strip.
DNA Helix | Two colored strands weave past each other, evoking a rotating double helix.
Quad Strobe | The strip is split into four segments that strobe in sequence.
Fireworks | Random expanding bursts of color that fade - also the winner celebration.
Starfield | Random white/blue stars twinkle on and fade, like a night sky.
Aurora | Slow drifting green/blue bands, like the northern lights.
VU Meter | Audio-reactive level bar (green/yellow/red) driven by the system's sound output.

Reactive show lighting: the strip also responds to play - a gold ripple on coin-up; on each hit a color flash keyed to the points that then leaves a level meter (1-8, green->yellow->red) lit until the next hit; a fireworks burst on a winner; and a red strobe on tilt.

Score lamps in play: the tens/hundreds lamps normally count up to the new total after each hit. A big hit (50 points or more) instead fires a quick 'crazy' lamp flourish - a few all-flash blinks and a fast double chase - and then settles back onto the real score. When no game is running and the attract light show is on, the score lamps also run a RANDOM attract pattern (Chase / Inside Out / Sweep / Cascade / Flash), refreshed each attract interval; it stops the moment a coin starts a game or you leave the Game Status screen.

# 7. The diagnostics panel - every control

## Diagnostics tab

Control | What it does
Switch test (Level 0-8 checkboxes) | A live input monitor - each checkbox ticks when its playfield switch fires. Use it to confirm every switch and its wiring.
Lamps: 10-90 / 100-400 / Winner / Game Over / Tilt | Toggle each physical score lamp/reel on or off to test the lamp, its driver, and the J2 harness. The button turns green while its lamp is lit.
Lamps: All | Lights every score lamp at once (and clears them again).
Lamps: Bulb Test | Walks every score lamp on-then-off one at a time (10, 20 ... 400, then Winner / Game Over / Tilt) so you can watch and confirm each bulb and its driver.
Lamps: PATTERN (dropdown + START/STOP) | Runs a score-lamp attract pattern - Chase, Inside Out, Sweep, Cascade, or Flash - on the physical lamps. START runs it; clicking again STOPs and clears.
Lighting > Patterns (dropdown + START) | Runs the selected WS2812b strip pattern (see section 6).
Lighting > Solid (RED/Green/Blue/Yellow/Purple/White) | Sets the whole strip to that solid color.
Lighting > Brightness (UP / Down / OFF) | Steps the strip brightness up or down; OFF blanks the strip.
Sound (Package + Sound + Play) | Previews one specific sound from a chosen package.
Solenoids (Winner Lock / Coin Lock) | Fires each solenoid so you can test the coil, TIP120 driver, fuse and flyback. The button turns blue while the coil is energized.
Hardware Status (GPIO1-4) | A live readout along the bottom of the tab showing which of the four FT232H boards are present - each board GREEN when enumerated, RED if missing/unplugged, with an ALL OK / n MISSING summary. Re-checked automatically every few seconds while the tab is open, so pulling a USB cable shows up on its own.
POST readout | Shows the power-on self-test result recorded at startup: 'POST: PASS', or 'POST: FAIL' naming the missing board.
View Log | Opens the on-screen log viewer - the tail of skillgame.log (recent events + errors) with a REFRESH button - so you don't have to dig the file out of %LOCALAPPDATA%.
Wiring Test | Opens the guided wiring test: it prompts you to activate each switch in turn (S0, S1, ...) and confirms each is wired to the pin the software expects, flagging any dead or miswired switch. SKIP / RESTART / CLOSE. Great when building or servicing the cabinet.
I/O Map | Opens a floating, always-on-top live pin map of all four FT232H boards. Trip a switch (input) or push any lamp/solenoid button (output) and the matching pin lights up - GREEN for an active input, AMBER for an energized output. It stays visible over the Diagnostics tab so you can watch pins as you push buttons; a quick way to confirm the software is driving/reading the pin you expect.

## Settings tab

Control | What it does
Volume Up / Down / Mute | Adjust or mute the Windows master volume; the readout shows the level (and MUTED).
Sound Package | Choose which sound-pack folder the game plays from.
Sound: Attract / Distract toggles | Enable/disable the attract (idle) and distract (on-hit) sound effects.
Lighting: State / Attract / Distract toggles | Enable/disable the strip's overall state, attract (idle) show, and distract (on-hit) bursts.
Operator Setup: Count-up Speed | Milliseconds per step of the score count-up sweep (lower = faster). Saved.
Operator Setup: Attract Light / Sound intervals | When no one is playing, the machine plays an idle attract light show and attract sound. These set how many seconds between each. Saved.
Operator Setup: Tilt Switch | Turn the tilt switch on or off - handy if a finicky tilt is ending games early. Saved.
Operator Setup: Quiet Hours | Enable an overnight master-volume cap, with editable Start Hour, End Hour, and Volume Cap %. Saved.
Operator Setup: SAVE | Writes the above to operator_settings.json next to the exe and applies them immediately (no restart).
Machine Info | Read-only service panel: app version, uptime since boot, and the sound / log / audits / config file paths.
Backup Audits | Writes a datestamped copy of the audit file next to the game - a quick safety copy.

Every button and control on the form has a hover tooltip explaining exactly what it does (including each Audits stat card and each Settings/Operator function). On the Diagnostics tab the buttons are colour-coded by section - amber = score lamps, cyan = LED strip, purple = sound, red = solenoids - so the groups read at a glance. The Game Status page shows a live clock and a framed STATUS tile (high score to beat, session tally, and quiet-hours status). The Settings page has the Machine Info panel (below the volume/sound/lighting boxes) and the SKILLGAME banner. Nothing overlaps.

# 8. Audits (the machine's books)

The Audits tab is a read-only service page, like the audits menu on a real arcade machine. It shows, in the same Seven-Segment style as the rest of the game:

- Headline cards: Games Played, Time Played, Winners, and Total Hits.
- High-score table (top 10), saved alongside the audits.
- Score-switch hits by level, with health coloring - a switch not exercised this power-cycle shows dim.
- Service buttons: RESET (erase audits + high scores, with confirmation - Total Games Played is permanent and is always kept) and EXPORT (write a CSV next to the exe). These act on the audit data, so they live here; the hardware tests (Bulb Test, board status) are on the Diagnostics tab and the DEMO self-test game is on the Game Status screen.
- The whole page is read-only - the numbers cannot be edited from the game.

The counts are kept in AuditStore and saved to skillgame_audits.json right next to the game exe, so they travel with the machine and survive restarts. They are loaded when the game opens, updated during play, and saved at each game end and on shutdown. To zero the books, delete that JSON file while the game is closed.

# 9. Reliability - logging & tests

- Logging: Log.cs writes timestamped lines to %LOCALAPPDATA%\SkillGame\skillgame.log (startup, hardware init success/failure, load errors). Check it first if something misbehaves.
- Unit tests: the SkillGame.Tests project (xUnit, 27 tests) covers the game rules with fake hardware/view/audio - coin arming, level gating, point accumulation, big-hit flourish vs normal count-up, winner, gobble, tilt, tilt-disable, and clear - plus operator-settings clamping/apply and a guard proving audio playback never throws when the sound files are missing. Run them with 'dotnet test' or Test Explorer in Visual Studio.
- The rules (GameEngine) depend only on small interfaces, so they run and test with no FT232H attached.

# 10. First-time setup

## 10.1 Development environment

- Visual Studio 2022 with the .NET 8 SDK.
- Open SkillGame.sln, restore NuGet packages, confirm dlls\FTD2XX_NET.dll is referenced.
- The solution is x64-only. Build the solution; the SkillGame.Tests project runs the rule tests.

## 10.2 FTDI driver

- Install the FTDI CDM driver.
- If the app can't find the devices, copy ftd2xx.dll into C:\Windows\System32 and SysWOW64.

## 10.3 Program the FT232H serial numbers

The software finds each board by serial, so each must be programmed and seated in the matching silk-labeled socket.

- Run FT_Prog -> DEVICES -> Scan and Parse.
- USB String Descriptors -> Serial Number = GPIO1 (then GPIO2/3/4) -> DEVICES -> Program -> reconnect.
- Seat the board programmed GPIOn into socket Un (U1=GPIO1 ... U4=GPIO4).

## 10.4 Sound files

Sounds load from C:\SkillGame\Sounds\. Create: Startup, Attract, Distract, Settings, and one folder per sound package with 10pts.wav ... 80pts.wav and gameover.wav. Point-sound keys use a space ('10 pts'), matching the file names and the diagnostics preview.

## 10.5 Kiosk / cabinet setup (optional)

- Auto-login to Windows.
- Boot splash (HackBGRT).
- Disable screen blanking/sleep.
- Hide the cursor.
- The form starts maximized and scales to the screen.

# 11. Wiring

Full detail - system diagram, the four driver circuits, external power with the ground bus, and the KiCad schematic - is in SkillGame_Wiring_Diagram.html; every pin is in SkillGame_GPIO_Map.html. Summary:

- Switch inputs: 3.3 V - switch - FT232H pin - 10 kOhm to GND (active-High).
- Lamps: FT pin -> 1 kOhm -> PN2222A -> lamp (out via harness connector J2).
- Solenoids: FT pin -> 1 kOhm -> TIP120 -> coil, with a 1N4004 flyback across the coil (fused F1/F2).
- NeoPixel: data from GPIO4 D1 (MOSI); power from the 5 V supply.
- All supplies share one common ground.

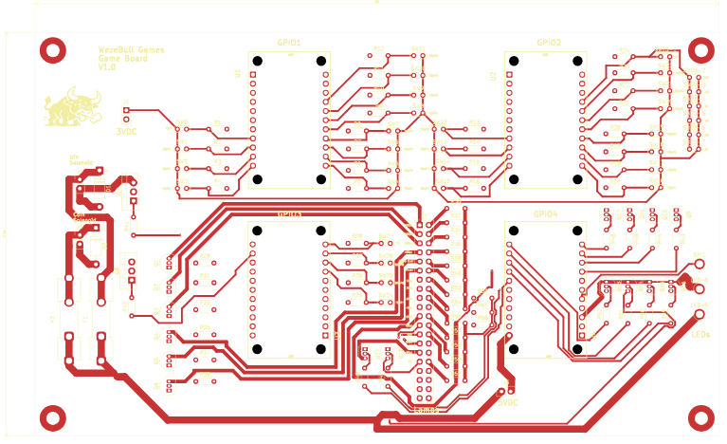
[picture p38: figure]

Game board (top copper) - FT232H sockets U1-U4 labeled with their serials.

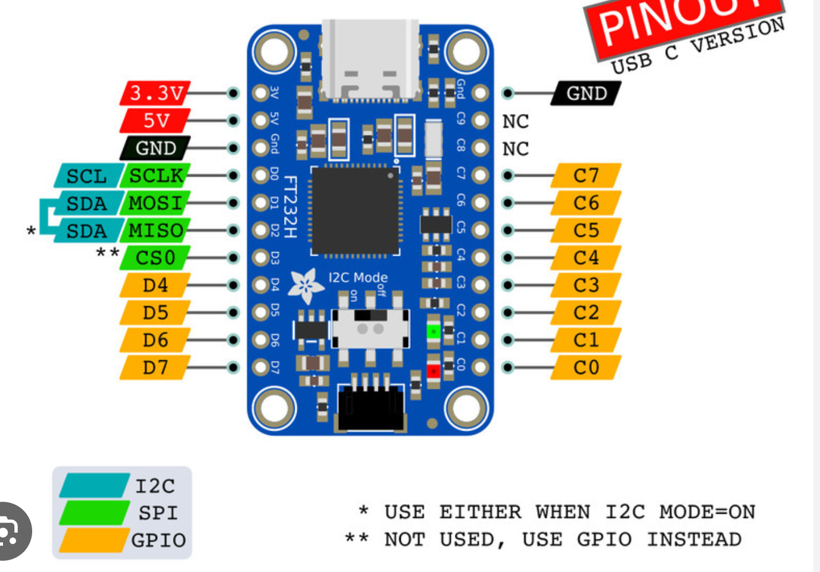
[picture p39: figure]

Adafruit FT232H pinout. D4-D7 / C0-C7 are the GPIO used; D0-D3 are SPI/MPSSE (only D1/MOSI).

# 12. Playing the game

- Insert a nickel - Coin Up (S0) arms the game at level 1.
- Flip the levers to send the nickel up the playfield.
- Land a hole in the current row - points added, score lamps count up to the new total, level advances.
- Reach a Row-8 (80-pt) hole - Winner lamp + win-lock solenoid.
- A gobble hole (S23) or Tilt (S27) ends the game.

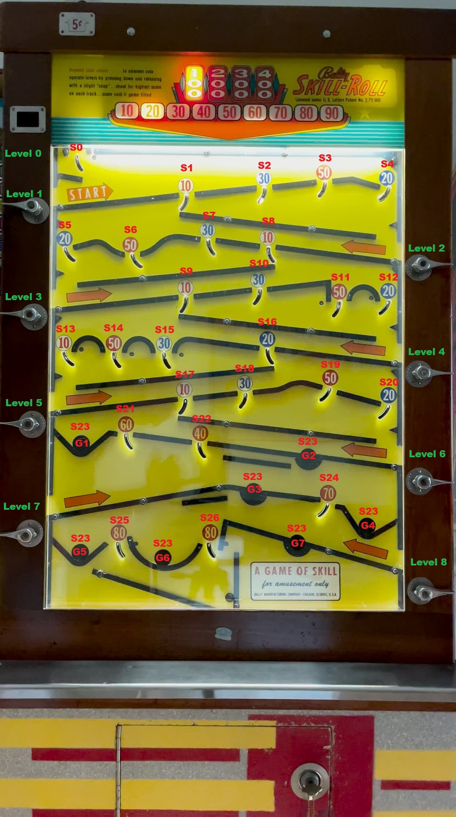
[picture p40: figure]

Playfield with switch (S0-S27) and gobble-hole (G1-G7) locations.

# 13. Troubleshooting

Symptom | Likely cause | Fix
'Hardware Not Ready' at startup | Not all 4 boards enumerated / serial not set | Confirm all 4 FT232H enumerate; program serials; check hub/cables (log has details). The form still opens and every tab is viewable - the game/lamp/LED functions just no-op, and Diagnostics shows 'POST: NO HARDWARE' - so you can work the diagnostics/audits screens with the boards unplugged.
A whole board's switches/lamps dead | Module in the wrong socket / serial mismatch | Put module GPIOn in socket Un (silk label).
No sound | Missing sound files / wrong path | Populate C:\SkillGame\Sounds\ subfolders.
A single lamp never lights | Driver / harness / wrong pin | Toggle it on the Diagnostics tab; check its PN2222A and the J2 harness.
Solenoid won't fire | Supply, TIP120, missing flyback, or blown fuse | Fire it on the Diagnostics tab; check supply & fuse; confirm TIP120 + 1N4004.
NeoPixel strip dark | 5 V supply or data pin | Power from 5 V (not USB); data on GPIO4 D1; check DIN direction.
Form looks huge/overlapping in the VS designer | 200% display + WinForms designer | Cosmetic only - it renders correctly at runtime; use 100% scaling or DPI-unaware designer mode.

# 14. Bill of materials

On-board electronics (from the KiCad schematic):

Qty | Part | Ref / value | Purpose
4 | Adafruit FT232H breakout (USB-C) | U1-U4 | USB -> GPIO / SPI
34 | SPST switch | SW0-SW27 (S23 = 7 gobble) | playfield hole switches
16 | NPN transistor | PN2222A | lamp drivers
2 | Darlington transistor | TIP120 (Q7, Q8) | solenoid drivers
2 | Diode | 1N4004 (D1, D2) | solenoid flyback
2 | Fuse | F1, F2 | solenoid protection
28 | Resistor | 10 kOhm | switch-input pull-downs
16 | Resistor | 1.0 kOhm | PN2222A base
2 | Resistor | 2.2 kOhm | TIP120 base
16 | Resistor | 220 Ohm | lamp current limit
2+ | Header | J1, J3 (power in) | 3.3 V / 5 V power
1 | 40-pin header | J2 | lamp harness
1 | LED-strip connector | SPI1 | WS2812b data + 5 V
4 | Mounting hole | H1-H4 | board mounting

External / system parts (not on the PCB):

Qty | Part | Purpose
1 | Windows mini-PC (16 GB, SSD) | game controller
1 | Powered USB hub | connects the 4 FT232H boards
1 | 10" capacitive touch monitor | diagnostics / audits display
1 | 3.3 V power supply | switch inputs
1 | 5 V power supply | WS2812b strip
1 | Lamp power supply | score / indicator lamps
1 | Solenoid power supply | coin-lock & win-lock coils
1 | WS2812b LED strip, 150 px | show lighting
2 | Solenoid | coin lock, win lock
16 | Lamps / bulbs | 10-90, 100-400, Game Over, Winner, Tilt
- | Wire, crimps, standoffs | assembly

# 15. Pin map reference

Logical pin numbers in code: D0-D7 = 0-7, C0-C7 = 8-15.

Board | Pad | # | Sw | Function | Row
GPIO1 | D4 | 4 | S0 | Coin Up
GPIO1 | D5 | 5 | S1 | 10 pts | R1
GPIO1 | D6 | 6 | S2 | 30 pts | R1
GPIO1 | D7 | 7 | S3 | 50 pts | R1
GPIO1 | C0 | 8 | S4 | 20 pts | R1
GPIO1 | C1 | 9 | S5 | 20 pts | R2
GPIO1 | C2 | 10 | S6 | 50 pts | R2
GPIO1 | C3 | 11 | S7 | 30 pts | R2
GPIO1 | C4 | 12 | S8 | 10 pts | R2
GPIO1 | C5 | 13 | S9 | 10 pts | R3
GPIO1 | C6 | 14 | S10 | 30 pts | R3
GPIO1 | C7 | 15 | S11 | 50 pts | R3
GPIO2 | D4 | 4 | S12 | 20 pts | R3
GPIO2 | D5 | 5 | S13 | 10 pts | R4
GPIO2 | D6 | 6 | S14 | 50 pts | R4
GPIO2 | D7 | 7 | S15 | 30 pts | R4
GPIO2 | C0 | 8 | S16 | 20 pts | R4
GPIO2 | C1 | 9 | S17 | 10 pts | R5
GPIO2 | C2 | 10 | S18 | 30 pts | R5
GPIO2 | C3 | 11 | S19 | 50 pts | R5
GPIO2 | C4 | 12 | S20 | 20 pts | R5
GPIO2 | C5 | 13 | S21 | 60 pts | R6
GPIO2 | C6 | 14 | S22 | 40 pts | R6
GPIO2 | C7 | 15 | S23 | Gobble G1-G7 | R6-8
GPIO3 | D4 | 4 | S24 | 70 pts | R7
GPIO3 | D5 | 5 | S25 | 80 pts | R8
GPIO3 | D6 | 6 | S26 | 80 pts | R8
GPIO3 | D7 | 7 | S27 | Tilt
GPIO3 | C0 | 8 | - | Coin Lock solenoid
GPIO3 | C1 | 9 | - | Win Lock solenoid
GPIO3 | C2 | 10 | - | 100 pt lamp
GPIO3 | C3 | 11 | - | 200 pt lamp
GPIO3 | C4 | 12 | - | 300 pt lamp
GPIO3 | C5 | 13 | - | 400 pt lamp
GPIO3 | C6 | 14 | - | Game Over lamp
GPIO3 | C7 | 15 | - | Winner lamp
GPIO4 | D1 | 1 | - | WS2812b data (SPI)
GPIO4 | D4 | 4 | - | 10 pt lamp
GPIO4 | D5 | 5 | - | 20 pt lamp
GPIO4 | D6 | 6 | - | 30 pt lamp
GPIO4 | D7 | 7 | - | 40 pt lamp
GPIO4 | C0 | 8 | - | 50 pt lamp
GPIO4 | C1 | 9 | - | 60 pt lamp
GPIO4 | C2 | 10 | - | 70 pt lamp
GPIO4 | C3 | 11 | - | 80 pt lamp
GPIO4 | C4 | 12 | - | 90 pt lamp
GPIO4 | C5 | 13 | - | Tilt lamp

# 16. Schematic & PCB notes

Both are electrically complete and correct - the software, spec, playfield and netlist all agree, and the board passes DRC with 0 violations and 0 unconnected nets. Two 'nicer for v2' notes (neither is required):

- Schematic: it is one flat B-size (11x17) sheet with ~140 parts. That is fine, but it is busy - the long wires carrying the GPIO3/GPIO4 outputs across to the J2 harness and the 220-Ohm bank are the clutter. Easiest cleanup: replace those long runs with net labels (stays one page). For a textbook-clean set, go hierarchical - one sheet per FT232H board. Also fill in the empty title block (Title / Rev / Date).
- PCB: correct and manufacturable but hand-routed and loose. The full step-by-step tidy-up plan is in SkillGame_PCB_v2_Layout_Plan.md (placement first, then route, ground stitching, net classes, rebalance).

# 17. Service & show features

## Added in this build

- Service tools (Diagnostics tab): a guided WIRING TEST that walks each switch and confirms it's on the right pin; a power-on self test (POST) that checks the boards + flashes the lamps/strip at startup and shows PASS/FAIL; an on-screen LOG VIEWER (tail of skillgame.log); and a live I/O MAP (floating window) that lights the actual FT232H pin - green for inputs, amber for outputs - as you trip a switch or push a button. Plus the BULB TEST (walks every lamp) and the Hardware Status board readout. All tests/diagnostics live on this tab.
- Operator Setup (Settings tab): tune and SAVE the score count-up speed, tilt on/off, and overnight quiet-hours cap (start/end/volume) to operator_settings.json - values that used to be hardcoded.
- Game Status: a DEMO GAME button that plays a full self-test game - score climbs, levels advance, lamps and sounds fire - with no coin or playfield, paced like a real game (about 12 seconds between scores so the sounds and light shows play out). Click it again (STOP DEMO) to cancel and reset the game to idle.
- Audits: a high-score table, per-switch health coloring (dim = not exercised this power-cycle), and RESET (with confirmation) + EXPORT-to-CSV. The Audits tab holds only the books; hardware tests moved to Diagnostics.
- Interface polish: the whole form uses rounded, glass-look buttons; the Game Status screen is now a proper scoreboard with a large SCORE readout as the hero element; and every control still scales to fill any screen resolution.
- Show lighting: reactive strip effects - coin ripple, points-keyed score flash, winner fireworks, tilt strobe - plus new selectable patterns Fireworks / Starfield / Aurora / VU Meter (audio-reactive).
- Deployment: a kiosk watchdog (SkillGame_Kiosk_Watchdog.ps1) that relaunches the game if it exits, with logon-registration instructions inside it.
- Optional quiet hours: caps the master volume overnight - off by default; enable it in QuietHours.cs (Enabled / StartHour / EndHour / QuietPercent).

## Status

Nothing major is outstanding - the earlier wish-list (extra diagnostics, audits + high scores, reactive show lighting, new patterns, VU meter, the persistent level meter, and the kiosk watchdog) is all implemented. 'Free-play vs coin' modes don't apply to this machine: the physical nickel is the gameplay (you flip the real coin up the playfield), so there is nothing to gate with credits.

# 18. Notes & to-do

Add your own build notes, changes, and open items here.

- (your notes...)

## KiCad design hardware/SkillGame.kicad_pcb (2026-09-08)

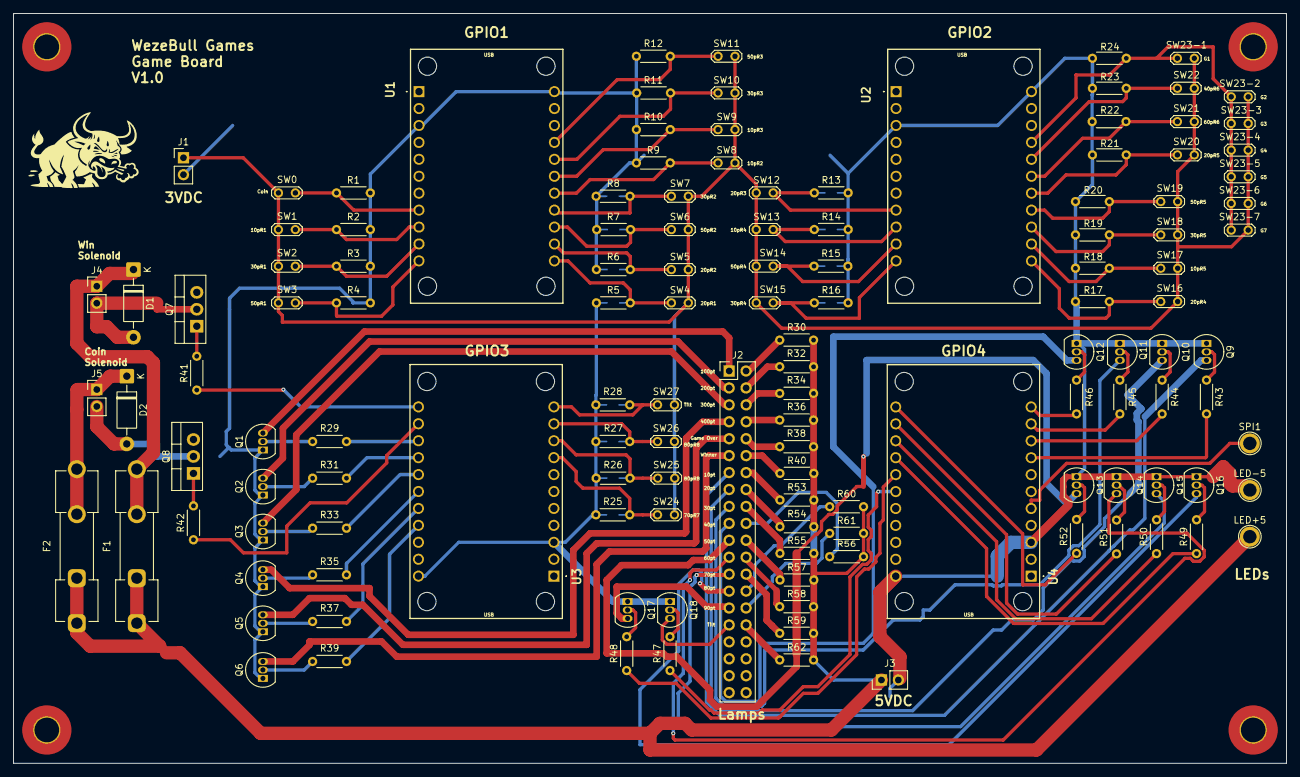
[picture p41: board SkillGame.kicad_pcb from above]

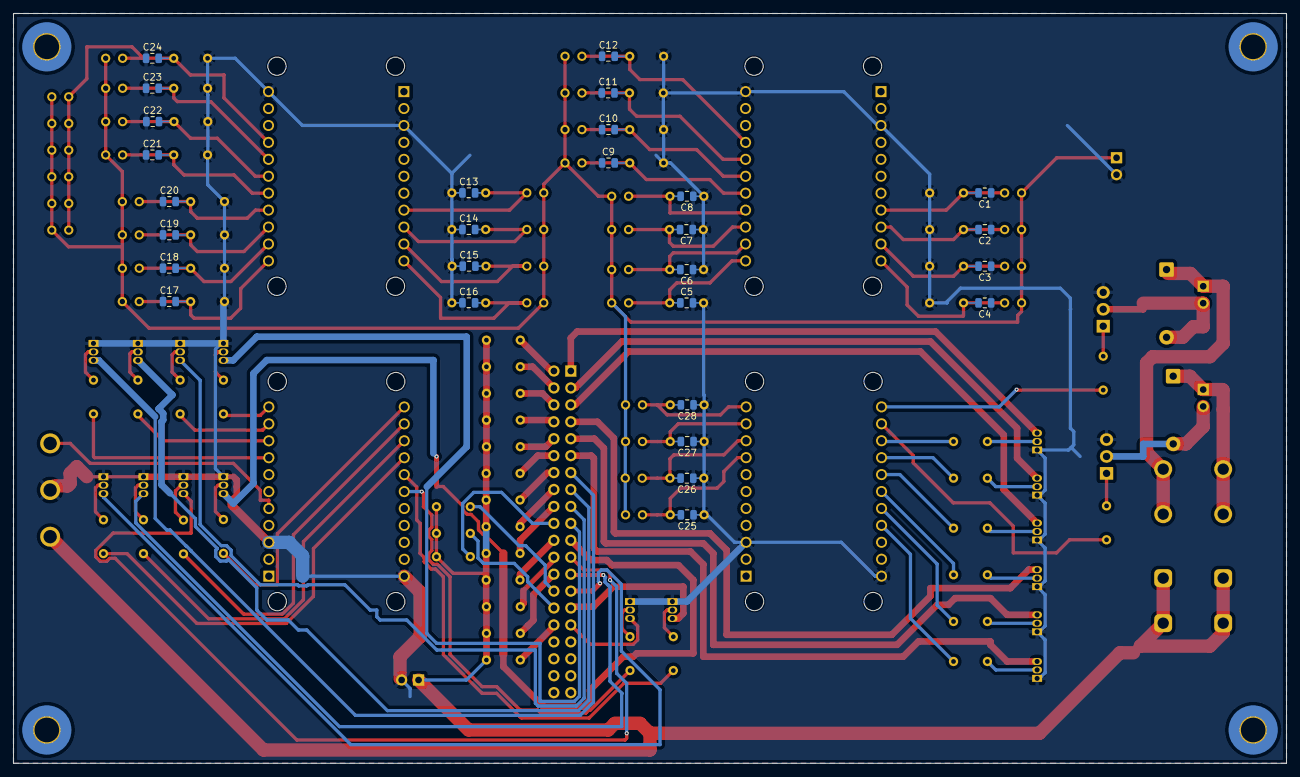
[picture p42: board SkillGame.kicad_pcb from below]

Board: 2 copper layers, 191.0 x 112.5 mm, 162 parts (28 on the bottom side), 104 nets.

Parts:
C1, C2, C3, C4, C5, C6, C7, C8, C9, C10, C11, C12, C13, C14, C15, C16, C17, C18, C19, C20, C21, C22, C23, C24, C25, C26, C27, C28: 100nF; C_0805_2012Metric
D1, D2: 1N4004; D_DO-41_SOD81_P10.16mm_Horizontal
F1, F2: Fuse; Fuseholder_Clip-5x20mm_Keystone_3517_Inline_P23.11x6.76mm_D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
H1, H2, H3, H4: MountingHole; MountingHole_3.7mm_Pad_TopBottom
J1, J3, J4, J5: Conn_01x02_Pin; PinHeader_1x02_P2.54mm_Vertical
J2: Conn_02x20_Odd_Even; PinHeader_2x20_P2.54mm_Vertical
LED+5: 5VDC+; TestPoint_Plated_Hole_D2.0mm
LED-5: 5VDC-; TestPoint_Plated_Hole_D2.0mm
Q1, Q2, Q3, Q4, Q5, Q6, Q9, Q10, Q11, Q12, Q13, Q14, Q15, Q16, Q17, Q18: PN2222A; TO-92_Inline
Q7, Q8: TIP120; TO-220-3_Vertical
R1, R2, R3, R4, R5, R6, R7, R8, R9, R10, R11, R12, R13, R14, R15, R16, R17, R18, R19, R20, R21, R22, R23, R24, R25, R26, R27, R28: 10k; R_Axial_DIN0204_L3.6mm_D1.6mm_P5.08mm_Horizontal
R29, R31, R33, R35, R37, R39, R43, R44, R45, R46, R47, R48, R49, R50, R51, R52: 1.00k; R_Axial_DIN0204_L3.6mm_D1.6mm_P5.08mm_Horizontal
R30, R32, R34, R36, R38, R40, R53, R54, R55, R56, R57, R58, R59, R60, R61, R62: 0 R; R_Axial_DIN0204_L3.6mm_D1.6mm_P5.08mm_Horizontal
R41, R42: 2.2k; R_Axial_DIN0204_L3.6mm_D1.6mm_P5.08mm_Horizontal
SPI1: SPI; TestPoint_Plated_Hole_D2.0mm
SW0, SW1, SW2, SW3, SW4, SW5, SW6, SW7, SW8, SW9, SW10, SW11, SW12, SW13, SW14, SW15, SW16, SW17, SW18, SW19, SW20, SW21, SW22, SW23-1, SW23-2, SW23-3, SW23-4, SW23-5, SW23-6, SW23-7, SW24, SW25, SW26, SW27: SW_DPST_x2; TestPoint_2Pads_Pitch2.54mm_Drill0.8mm
U1, U2, U3, U4: Conn_01x11_Socket_FT232H; FT232H_Final

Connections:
GNDREF: C1.1, C2.1, C3.1, C4.1, C5.2, C6.1, C7.1, C8.1, C9.1, C10.1, C11.1, C12.1, C13.1, C14.1, C15.1, C16.1, C17.1, C18.1, C19.1, C20.1, C21.1, C22.1, C23.1, C24.1, C25.1, C26.1, C27.1, C28.1, J1.2, J3.2, LED-5.1, Q1.1 (E), Q2.1 (E), Q3.1 (E), Q4.1 (E), Q5.1 (E), Q6.1 (E), Q7.3 (E), Q8.3 (E), Q9.1 (E), Q10.1 (E), Q11.1 (E), Q12.1 (E), Q13.1 (E), Q14.1 (E), Q15.1 (E), Q16.1 (E), Q17.1 (E), Q18.1 (E), R1.2, R2.2, R3.2, R4.2, R5.2, R6.2, R7.2, R8.2, R9.2, R10.2, R11.2, R12.2, R13.2, R14.2, R15.2, R16.2, R17.2, R18.2, R19.2, R20.2, R21.2, R22.2, R23.2, R24.2, R25.2, R26.2, R27.2, R28.2, U1.3 (GND), U1.22 (GND), U2.3 (GND), U2.22 (GND), U3.3 (GND), U3.22 (GND), U4.3 (GND), U4.22 (GND)
unnamed: D1.2 (A), J4.2, Q7.2 (C)
unnamed: D1.1 (K), F1.2, J4.1
unnamed: D2.2 (A), J5.2, Q8.2 (C)
unnamed: D2.1 (K), F2.2, J5.1
unnamed: J1.1, SW0.1 (A), SW1.1 (A), SW2.1 (A), SW3.1 (A), SW4.1 (A), SW5.1 (A), SW6.1 (A), SW7.1 (A), SW8.1 (A), SW9.1 (A), SW10.1 (A), SW11.1 (A), SW12.1 (A), SW13.1 (A), SW14.1 (A), SW15.1 (A), SW16.1 (A), SW17.1 (A), SW18.1 (A), SW19.1 (A), SW20.1 (A), SW21.1 (A), SW22.1 (A), SW23-1.1 (A), SW23-2.1 (A), SW23-3.1 (A), SW23-4.1 (A), SW23-5.1 (A), SW23-6.1 (A), SW23-7.1 (A), SW24.1 (A), SW25.1 (A), SW26.1 (A), SW27.1 (A)
unnamed: J2.1, Q1.3 (C)
unnamed: J2.2, R30.1
unnamed: J2.3, Q2.3 (C)
unnamed: J2.4, R32.1
unnamed: J2.5, Q3.3 (C)
unnamed: J2.6, R34.1
unnamed: J2.7, Q4.3 (C)
unnamed: J2.8, R36.1
unnamed: J2.9, Q5.3 (C)
unnamed: J2.10, R38.1
unnamed: J2.11, Q6.3 (C)
unnamed: J2.12, R40.1
unnamed: J2.13, Q9.3 (C)
unnamed: J2.14, R53.1
unnamed: J2.15, Q10.3 (C)
unnamed: J2.16, R54.1
unnamed: J2.17, Q11.3 (C)
unnamed: J2.18, R55.1
unnamed: J2.19, Q12.3 (C)
unnamed: J2.20, R56.1
unnamed: J2.21, Q13.3 (C)
unnamed: J2.22, R57.1
unnamed: J2.23, Q14.3 (C)
unnamed: J2.24, R58.1
unnamed: J2.25, Q15.3 (C)
unnamed: J2.26, R59.1
unnamed: J2.27, Q16.3 (C)
unnamed: J2.28, R60.1
unnamed: J2.29, Q17.3 (C)
unnamed: J2.30, R61.1
unnamed: J2.31, Q18.3 (C)
unnamed: J2.32, R62.1
unnamed: F1.1, F2.1, J3.1, LED+5.1, R30.2, R32.2, R34.2, R36.2, R38.2, R40.2, R53.2, R54.2, R55.2, R56.2, R57.2, R58.2, R59.2, R60.2, R61.2, R62.2
unnamed: Q1.2 (B), R29.2
unnamed: Q2.2 (B), R31.2
unnamed: Q3.2 (B), R33.2
unnamed: Q4.2 (B), R35.2
unnamed: Q5.2 (B), R37.2
unnamed: Q6.2 (B), R39.2
unnamed: Q7.1 (B), R41.2
unnamed: Q8.1 (B), R42.2
unnamed: Q9.2 (B), R43.1
unnamed: Q10.2 (B), R44.1
unnamed: Q11.2 (B), R45.1
unnamed: Q12.2 (B), R46.1
unnamed: Q13.2 (B), R52.2
unnamed: Q14.2 (B), R51.2
unnamed: Q15.2 (B), R50.2
unnamed: Q16.2 (B), R49.2
unnamed: Q17.2 (B), R48.2
unnamed: Q18.2 (B), R47.2
unnamed: C1.2, R1.1, SW0.2 (B), U1.8 (D4)
unnamed: C2.2, R2.1, SW1.2 (B), U1.9 (D5)
unnamed: C3.2, R3.1, SW2.2 (B), U1.10 (D6)
unnamed: C4.2, R4.1, SW3.2 (B), U1.11 (D7)
unnamed: C5.1, R5.1, SW4.2 (B), U1.12 (C0)
unnamed: C6.2, R6.1, SW5.2 (B), U1.13 (C1)
unnamed: C7.2, R7.1, SW6.2 (B), U1.14 (C2)
unnamed: C8.2, R8.1, SW7.2 (B), U1.15 (C3)
unnamed: C9.2, R9.1, SW8.2 (B), U1.16 (C4)
unnamed: C10.2, R10.1, SW9.2 (B), U1.17 (C5)
unnamed: C11.2, R11.1, SW10.2 (B), U1.18 (C6)
unnamed: C12.2, R12.1, SW11.2 (B), U1.19 (C7)
unnamed: C13.2, R13.1, SW12.2 (B), U2.8 (D4)
unnamed: C14.2, R14.1, SW13.2 (B), U2.9 (D5)
unnamed: C15.2, R15.1, SW14.2 (B), U2.10 (D6)
unnamed: C16.2, R16.1, SW15.2 (B), U2.11 (D7)
unnamed: C17.2, R17.1, SW16.2 (B), U2.12 (C0)
unnamed: C18.2, R18.1, SW17.2 (B), U2.13 (C1)
unnamed: C19.2, R19.1, SW18.2 (B), U2.14 (C2)
unnamed: C20.2, R20.1, SW19.2 (B), U2.15 (C3)
unnamed: C21.2, R21.1, SW20.2 (B), U2.16 (C4)
unnamed: C22.2, R22.1, SW21.2 (B), U2.17 (C5)
unnamed: C23.2, R23.1, SW22.2 (B), U2.18 (C6)
unnamed: C24.2, R24.1, SW23-1.2 (B), SW23-2.2 (B), SW23-3.2 (B), SW23-4.2 (B), SW23-5.2 (B), SW23-6.2 (B), SW23-7.2 (B), U2.19 (C7)
unnamed: C25.2, R25.1, SW24.2 (B), U3.8 (D4)
unnamed: C26.2, R26.1, SW25.2 (B), U3.9 (D5)
unnamed: C27.2, R27.1, SW26.2 (B), U3.10 (D6)
unnamed: C28.2, R28.1, SW27.2 (B), U3.11 (D7)
unnamed: R41.1, U3.12 (C0)
unnamed: R42.1, U3.13 (C1)
unnamed: R29.1, U3.14 (C2)
unnamed: R31.1, U3.15 (C3)
unnamed: R33.1, U3.16 (C4)
unnamed: R35.1, U3.17 (C5)
unnamed: R37.1, U3.18 (C6)
unnamed: R39.1, U3.19 (C7)
unnamed: R52.1, U4.12 (C0)
unnamed: R51.1, U4.13 (C1)
unnamed: R50.1, U4.14 (C2)
unnamed: R49.1, U4.15 (C3)
unnamed: R48.1, U4.16 (C4)
unnamed: R47.1, U4.17 (C5)
unnamed: SPI1.1, U4.5 (D1)
unnamed: R43.2, U4.8 (D4)
unnamed: R44.2, U4.9 (D5)
unnamed: R45.2, U4.10 (D6)
unnamed: R46.2, U4.11 (D7)

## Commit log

2026-09-07 Initial commit — SkillGame: WPF app, engine core + tests, KiCad hardware, docs
    Bally Skill-Roll recreation driving 4x FT232H over USB. Includes the fixed
    KiCad design (TIP120 collector/emitter corrected, no-connect flags added),
    the sourced BOM, and the IKEA-style assembly guide.
    [SkillGame BOM (sourced).xlsx, SkillGame.kicad_pcb, SkillGame.kicad_sch]
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2026-09-07 Add #555 wedge LED lamp bulbs + sockets to the BOM
    The 16 score lamps (10-400 + Winner/Game Over/Tilt) and their sockets
    were missing. Added #555 T10 wedge LED bulbs (6.3 V, non-polar, built-in
    resistor) and pigtail wedge sockets to the sourced BOM, the schematic-page
    BOM image, and the assembly guide. BOM total is now $473.52.
    [SkillGame BOM (sourced).xlsx]
2026-09-07 Show the LED lamps in the schematic; double the 100/200/300/400 holes
    - Schematic: added all 16 score-lamp bulbs as #555 wedge LED symbols, with
    the 100/200/300/400 holes drawing TWO bulbs each (parallel, same output)
    for double brightness. Non-polar bulbs; ERC clean.
    - The board's lamp resistors R30-R62 are now 0 R links (schematic + PCB) --
    the pre-resistored #555 bulb self-limits and a 6.3 V bulb is safely
    under-driven on the 5 V rail. DRC clean.
    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
    [SkillGame BOM (sourced).xlsx, SkillGame.kicad_pcb, SkillGame.kicad_sch]
2026-09-07 Add wiring harnesses, playfield maps, F3 cable, and switch sourcing
    - Wiring harnesses for the lamps and switches: flat diagrams with every
    solder point, 3D cable views, and playfield/backglass maps showing where
    each lamp socket and switch lands (switch positions traced from the real
    Skill-Roll board).
    - Inline fuse cable (F3): dedicated diagram + 3D view; pinned the holder to
    a real part (uxcell 18 AWG inline, B07SM5KYZ7).
    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
    [SkillGame BOM (sourced).xlsx]
2026-09-07 Polish harness art: proper lit #555 bulb drawings + ground-path notes
    - Redrew the lamp glyph as a real lit #555 wedge bulb (frosted envelope,
    warm glow, emission core, wedge base) across the harness and playfield art.
    - Added the ground-path note to both harnesses: ground closes on the board
    (10k pull-down for switches, transistor emitter for lamps) — each socket/
    switch is just 2 leads. Noted the optional 100nF input debounce cap.
2026-09-08 Add 28 switch-input debounce caps (100 nF) to the board
    - Schematic: added C1-C28, one 100 nF cap from each switch input to GND,
    in parallel with the 10k pull-down (~1 ms RC debounce + noise filter on
    the long playfield leads). Enlarged the sheet to fit the cap bank. ERC at
    the benign baseline; all 28 netlist-verified across input<->GND.
    - PCB: placed all 28 as 0805 SMD on the back, next to each pull-down (GND
    pad on the pour, input to the pull-down). 3D back render updated.
    - BOM + guide + app schematic images updated (BOM total now $507.16, guide
    24 pages with a debounce-cap step). Synced to the live OneDrive KiCad.
    [SkillGame BOM (sourced).xlsx, SkillGame.kicad_pcb, SkillGame.kicad_sch]
2026-09-08 App: note the 100 nF input debounce caps in the switch-matrix block
2026-09-08 PCB: DRC 0/0 - drop 2 redundant GND tracks under the pour
    The two long B.Cu GND tracks were already covered by the GND pour; with the
    new cap pads in the pour they tripped a spurious cli-DRC clearance flag.
    Removing them (pour keeps GND connected - 0 unconnected) makes the board
    fully DRC clean.
    [SkillGame.kicad_pcb]
2026-09-08 Switches: spec the arcade coin switch (85mm wire actuator)
    The right part is a coin switch - a snap-action microswitch with a long
    thin wire actuator (like the Bally original). The wire pokes up through a
    playfield slot and the rolling coin trips it; the long wire = feather-light
    force. Mounts hidden under the playfield, wires like any SPDT switch (no
    board changes). $3.99 ea (DIY Retro Arcade), ~$2 in 10-packs. Updated the
    BOM, guide, README and redrew the switch glyph to match. BOM now $610.86.
    [SkillGame BOM (sourced).xlsx]
2026-09-08 Add a board wiring reference: labeled connectors + switch-input pin map
    - Labeled top-view board (every connector + GPIO socket called out: J1-J5,
    J2 lamp header, SPI/LED strip, GPIO1-4).
    - Full switch-input table: each S0-S27 -> GPIO board + FT232H pin (D4-D7/
    C0-C7) + what it scores, with how-to-wire notes (COM to 3.3V bus, NO to
    the pin, 7 gobble in parallel on S23). So the board can be wired from the
    wire side. Added both as a Wiring reference section in the guide.
2026-09-08 App: add BOARD WIRING + INPUT MAP quick-access buttons on the schematic page
    Two new reference blocks/buttons pull up the labeled board (where every
    connector/wire lands) and the switch-input pin map right on the mini-PC at
    the board. Re-spaced the reference panel to fit all eight docs.
2026-09-08 App: add a CABLES + WIRING reference bar along the bottom of the schematic page
    Seven small slate buttons pop up the harness/cable drawings full-screen
    (lamp harness 2D/3D + on-board, switch harness 2D/3D + on-playfield, fuse
    cable). Added an image-only ShowImage() opener so these need no diagram
    block, and a 4th grid row for the bar.
2026-09-09 Remove the harness drawings; keep the labeled board + input map
    Pulled the cable-harness illustrations (lamp/switch harness 2D+3D, playfield
    maps, fuse cable) from the app, guide and repo. Kept the useful references:
    BOARD WIRING (labeled connectors) and INPUT MAP (switch pin table), plus the
    schematic. Coin-switch note moved onto the input-map page. Also fixed the
    BOARD WIRING / INPUT MAP button width (label was clipping).
2026-09-09 Solenoids: pulse the spring-return locks, never hold them energized
    The Win-Lock and Coin-Lock are spring-return coils (plunger out at rest
    blocks a coin with no power; a pulse retracts it to drop the coin). The
    old Winner() held the Win-Lock on for the rest of the game, which would
    cook the intermittent-duty coil.
    - Winner() now lights the LEDs only; the winning coin is held by the
    spring, and released by a pulse on the next coin-up.
    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
    [SkillGame BOM (sourced).xlsx]
2026-09-09 Hardware: gate the design rules at fab minimums
    The board's DRC minimums were unset (0), so a clean pass wasn't gated on
    anything. Set real 2-layer fab floors — min track 0.15 mm, min clearance
    0.15 mm, min hole-to-hole 0.5 mm (through-hole 0.3 mm and edge 0.5 mm were
    already fine). DRC still passes 0/0; the actual geometry (min track
    0.20 mm, min drill 0.30 mm, min annular 0.15 mm) sits above these, so
    future edits now get caught before fab.
2026-09-12 Cap strip brightness, stagger coil pulses, and spec one 5V supply
    Firmware:
    - Global WS2812b brightness cap (LightFunctions.MaxBrightness = 0.40).
    Full white on 150 px is ~9 A; every pattern now writes through a capped
    SetPixel so a worst-case frame stays under ~3.6 A. Physical strip only;
    the on-screen preview is unaffected.
    - PulseSolenoid takes a start delay; a post-win coin-up now fires Coin-Lock
    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
    [SkillGame BOM (sourced).xlsx]
2026-10-02 Add in-app software updater + hosting
    Service → Check for Updates: fetches version.json from the repo (raw URL),
    shows the release notes, downloads the zip with a progress bar, verifies its
    SHA-256, then hands off to an external step that swaps the files in once the
    app exits and reboots the machine.
    - Updater.cs: check/download/verify/apply. Install version read from
    version.txt beside the exe (falls back to the assembly version).
    - UpdateDialog.cs: themed check → notes → progress → install flow.
    - Hosting under update/: version.json manifest + a v1.0.1 test release zip,
    served free over raw.githubusercontent (repo is public).
    - tools/publish-update.ps1: one command to build, z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
2026-10-02 Theme: classy wood & brass; warm the marquee
    Collapse the old multi-accent (gold/cyan/green/purple/red/teal) scheme into
    one warm family — walnut/espresso surfaces, a single antique-brass accent,
    parchment text, and earthy tones (patina/olive/bronze/oxblood/taupe) for the
    few semantic colors. Most screens re-skin from the shared App.xaml palette;
    the schematic group accents and two dark-blue card backgrounds are remapped
    to match.
    Marquee: the on-screen SKILLGAME sign no longer renders the rainbow strip —
    it glows warm maple/amber (WarmGlow), following the strip's motion and
    brightness but never its hue, like a real incandescent bulb marquee. All the
    "on the fritz" flicker/spark/blink c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
2026-10-02 Harden the updater: no reboot / temp script, add rollback + auto-check
    The old install step dropped a .cmd in %TEMP%, ran cmd.exe, and rebooted the
    PC — which endpoint security (Cortex XDR) flags as malware behavior. The
    updater now just unzips + copies + relaunches the app:
    - Full builds hand off to a staged copy of the exe (run from _staged) to swap
    the locked files once the old instance exits; notes-only updates apply in
    place. No cmd.exe, no temp script, no PC reboot.
    - Keeps the previous version in _backup so the operator can ROLL BACK
    (Service → Check for Updates → Roll back to vX) — pick old vs new.
    - Background check on app boot + every 6 h; when a newer version exists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
2026-10-02 Themes: 11 presets + per-theme playfield art
    Add Vintage, Maple, Midnight, Synthwave, Lava, Circuit and Galaxy to the
    theme picker (now 11). Each theme also reskins the playfield: the loaders use
    C:\SkillGame\playfields\playfield_<Theme>.png when present (geometry-matched
    to the original, so coin paths still line up) and fall back to playfield.png.
2026-10-02 Docs: cover themes + the in-app updater; refresh screenshots to the wood look
    README Features now list the 11-theme picker and the in-app updater (install
    any version forward or back, no PC reboot); CHANGELOG has an Unreleased
    section; Game/Schematic/Diagnostics/Service screenshots refreshed to the wood
    theme + original playfield.
2026-10-02 Docs: add a themes gallery + a Software updates section to the README
    - New Themes section with an 11-board gallery image (docs/themes.png) built
    from the themed playfields.
    - New Software updates section: how the operator installs/rolls back any
    version, and how to cut a release with tools/publish-update.ps1.
    - Link the update/ folder + versions.json; drop a stray closing tag.
2026-10-02 Add a 12th theme (Ruby) and make the theme chips a tidy even grid
    Ruby — deep garnet & gold jewel look. Twelve themes now fill the Settings
    picker in an even 2×6 grid (uniform-width chips, so no odd leftover row).
    The matching Ruby playfield is generated by the skinner (CNC side); until it
    lands the theme falls back to the wood board.
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2026-10-03 Fix the boards-missing tombstone clipping at the top of Diagnostics
    When all boards are gone the bot froze wherever it was roaming; up high the
    tombstone (it sits ~46px above him) clipped at the page top and crowded the
    DIAGNOSTICS title. Park the knocked-out bot on the floor so the stone always
    has headroom.
2026-10-03 Diagnostics: disable each board's hardware tests when that board is missing
    Tests used to stay clickable with no boards (they just no-op'd). Now they're
    gated per board: GPIO3 drives the 100-400 reels, Winner/Game-Over and both
    lock coils; GPIO4 drives the 10-90 lamps, Tilt and the LED strip. So with a
    board absent its solenoid / LED / reel controls grey out, whole-backglass
    lamp patterns + bulb test need both lamp boards, and anything mid-run on a
    dropped board stops. Self-Test and All-Off stay live.
2026-10-03 Release v1.1.0
    Cut the real 1.1.0 release so the in-app updater serves everything since
    1.0.1: 12 themes + per-theme playfields, the original wood board, the
    hardened install-any-version updater, per-board Diagnostics gating, the warm
    marquee and the tombstone fix. version.json now points at v1.1.0 and
    versions.json lists 1.1.0 / 1.0.1 / 1.0.0.
